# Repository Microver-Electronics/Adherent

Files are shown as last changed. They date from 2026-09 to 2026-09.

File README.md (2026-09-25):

<p align="center">
  Adherent360 APDU — 70 lanes, 10 LANECTRL assemblies, four controller roles
</p>

<p align="center">
  <a href="SYS/ADHERENT_Electrical_Tables.xlsx"><strong>Component spreadsheet</strong></a> &nbsp; · &nbsp;
  <a href="SYS/ADHERENT_System_Wiring_Diagram.png"><strong>System diagram</strong></a> &nbsp; · &nbsp;
  <a href="SYS/ADHERENT_Harness_Wiring_Diagram.png"><strong>Harness diagram</strong></a> &nbsp; · &nbsp;
  <a href="SYS/ADHERENT_Design_Review.pptx"><strong>Design presentation</strong></a> &nbsp; · &nbsp;
  <a href="SYS/ADHERENT_Project_Review.md"><strong>Review findings</strong></a>
</p>

## The project

Adherent360 APDU is an automated pharmaceutical dispensing system built around **70 conveyor lanes**, a gantry, a labeling mechanism and monitored access doors. This repository holds the electrical architecture, component registers, mechanical references and planned hardware/firmware work for the system.

**Current system documents use stable, revision-free filenames.** Electrical design documentation is maintained by **Blackocean Technologies** in the **Microver Electronics / Adherent** repository.

> [!IMPORTANT]
> This is a design-review baseline. Components marked **TBC**, **candidate** or **HOLD** still need selection or engineering validation. LANECTRL Altium design files and exports are present; production release is not confirmed. Firmware/application implementations have not been added yet.

## 🗂️ Start with the documents

- **[Components and part numbers](SYS/ADHERENT_Electrical_Tables.xlsx)** — One sheet with 32 grouped entries, matching diagram references, part numbers, clickable source and CAD links, locations and rough dimensions.
- **[Mechanical BOM](MEC/ADHERENT_Mechanical_BOM.xlsx)** — gantry parts and mechanical procurement references.
- **[Design review presentation](SYS/ADHERENT_Design_Review.pptx)** — architecture, confirmed decisions and questions to resolve.
- **[Project decisions](brain.md)** — working assumptions, naming conventions and current scope.

Included components and interface positions are identified separately from purchased assemblies. Do not sum every spreadsheet row as an independent purchase quantity.

## 🔌 Electrical system

<a href="SYS/ADHERENT_System_Wiring_Diagram.png">
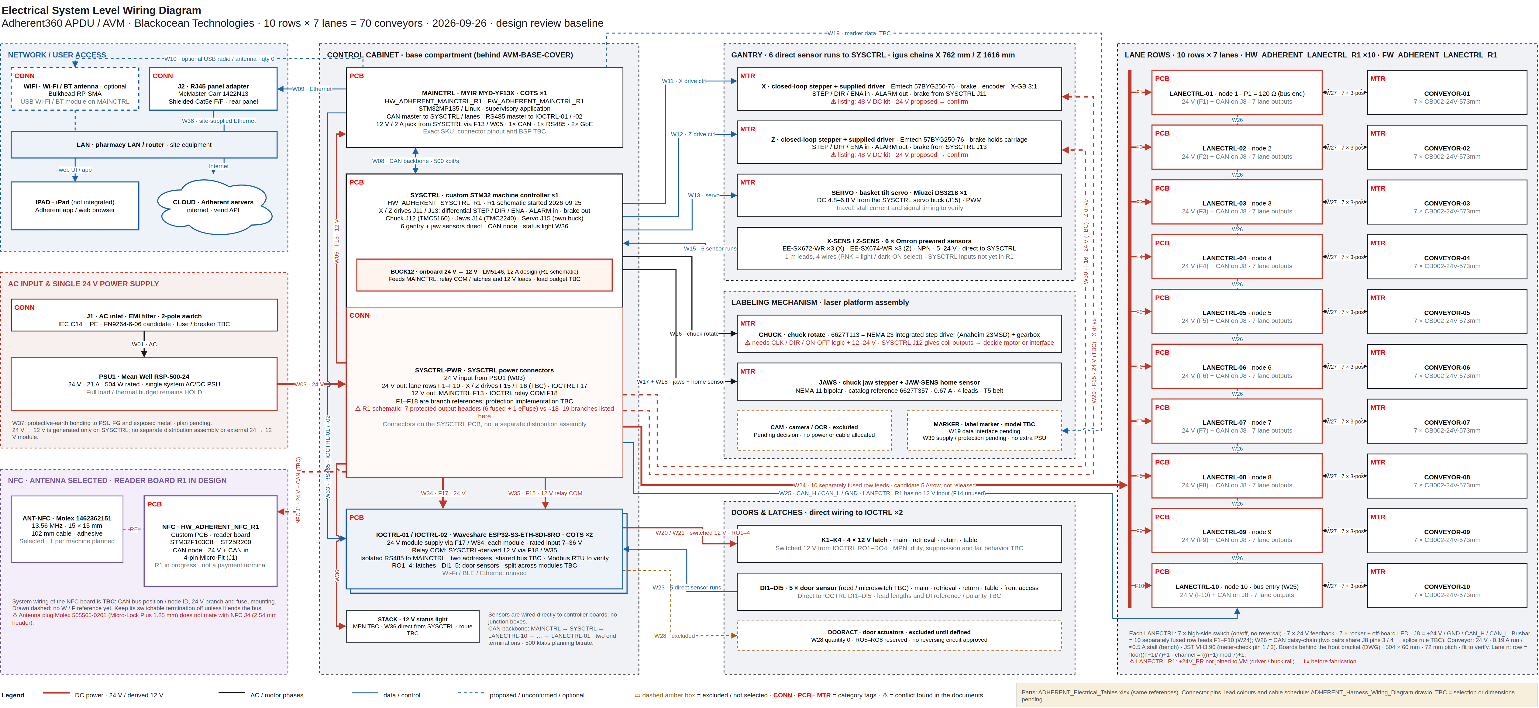
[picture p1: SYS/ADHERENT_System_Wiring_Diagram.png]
Electrical system wiring diagram with red CONN, PCB and MTR category tags
  
</a>

**[Open full-size PNG](SYS/ADHERENT_System_Wiring_Diagram.png)** · **[Edit in draw.io](SYS/ADHERENT_System_Wiring_Diagram.drawio)**

**Pin-level harness:** [ADHERENT_Harness_Wiring_Diagram](SYS/ADHERENT_Harness_Wiring_Diagram.drawio) ([PNG](SYS/ADHERENT_Harness_Wiring_Diagram.png)) shows every device with its product photo, connector pins and lead colours. Its draw.io layers are the build steps (AC → 24 V → branches → CAN → Ethernet / RS485 → drives → labeling → sensors → doors → lane rows), and two further pages hold the cable schedule and the connector reference. Interface conflicts found in the documents are flagged in red there.

Red, bold corner tags identify **CONN** connectors, **PCB** controller boards and **MTR** motor assemblies. These are category labels; the existing board, connector and cable identifiers remain the references used in the schedules.

- **Power:** one Mean Well **RSP-500-24**, rated 24 V / 21 A / 504 W. SYSCTRL generates the derived 12 V rail on board; converter selection and the full load budget remain open.
- **Control network:** CAN links MAINCTRL, SYSCTRL and the ten LANECTRL boards. The two IOCTRL modules (IOCTRL-01, IOCTRL-02) use a separate RS485 connection to MAINCTRL; bus topology and addressing are TBC.
- **Site connection:** McMaster-Carr **1422N13** rear-panel Ethernet adapter, quantity one. The iPad is external and uses the site network.
- **Direct sensors:** six gantry sensors connect to SYSCTRL; five door sensors connect to IOCTRL (split between the two modules TBC). **No junction boxes.**
- **IOCTRL power:** 24 V supplies each module; a separate SYSCTRL-derived 12 V feed supplies the latch relay contacts. Feed branches for the second module are TBC.

### NFC antenna

**Molex 1462362151** is selected: 13.56 MHz, 15 x 15 mm, adhesive mount, 102 mm cable. The NFC reader/front-end, host interface and power budget remain open under O16; no payment terminal is selected. [Supplier listing](https://www.digikey.com/en/products/detail/molex/1462362151/15204370).

The presentation covers the used system interfaces and current SYSCTRL/NFC architecture. Use the single-sheet parts workbook for part numbers, source links and mounting references.

## 🧩 Four controller roles

### 🟦 MAINCTRL — supervisory control

**MYIR MYD-YF13X · purchased board · 1 assembly**  
Planned Linux application, site/server communication, CAN master and RS485 master. Exact order code, populated interfaces and BSP require confirmation. [Hardware folder →](HW/HW_ADHERENT_MAINCTRL_R1)

### 🟪 SYSCTRL — machine control

**Custom STM32 PCB · 1 assembly**  
Gantry and labeling interfaces, sensors, servo and auxiliary outputs, plus onboard 24 V-to-12 V conversion. [Hardware folder →](HW/HW_ADHERENT_SYSCTRL_R1)

### 🟩 LANECTRL — conveyor rows

**Custom STM32G0B1 PCB · 10 assemblies · R1 placed and routed, not released**  
Seven conveyor channels per row, switched on/off by two TPS4H160 high-side switches with current sensing and fault reporting. Each lane has a PCB-mounted rocker switch that is hardware-ANDed with the MCU enable, a 24 V dry-contact feedback input and an off-board lane LED. Each board takes 24 V and CAN on one 4-pin Micro-Fit (+24 V / GND / CANH / CANL). Lane connectors are 3-pin Micro-Fit (24 V / GND / SIGNAL). The CAN node ID is set with a DIP switch and termination with a jumper. The PCB is 504 × 60 mm with 4 layers. Ten rows provide **70 channels**. [Hardware folder →](HW/HW_ADHERENT_LANECTRL_R1)

> [!WARNING]
> LANECTRL R1 schematic: the protected 24 V rail (`+24V_PR`) is not connected to the driver/buck rail (`VM`). Fix this and regenerate the netlist, BOM and PDF before fabrication. See [brain.md](brain.md#lanectrl--custom-pcb-quantity-10).

### 🟧 IOCTRL — door inputs and latch outputs

**Waveshare ESP32-S3-ETH-8DI-8RO · purchased board · 2 assemblies (IOCTRL-01, IOCTRL-02)**  
Eight relays and eight isolated digital inputs per module, 16 of each in total. The baseline allocates four latch outputs and five door-sensor inputs; their split between the two modules and the second module's additional functions are TBC. RS485 firmware behavior needs validation. [Hardware folder →](HW/HW_ADHERENT_IOCTRL_R1)

**Two custom PCB designs, eleven custom assemblies, three purchased controller assemblies (MAINCTRL ×1, IOCTRL ×2).**

## ⚙️ Mechanical integration

- [Machine assembly STEP](MEC/AVM-FRAME-MAINASSEMBLY_V4.STEP)
- [LANECTRL front-bracket DWG](MEC/01_CAD_MODELS/Draw%C4%B1ng/LANE%20DRAWING%20SPACE%20FOR%20UMIT.DWG)
- [Board STEP models and qualification notes](MEC/Board_STEP_Models/README.md)
- [Conveyor supplier reference](SYS/Conveyor%20belt%28CB002-24V-573mm%29.pdf)

The front bracket follows the supplied DWG. LANECTRL R1 is 504 × 60 mm with 8 × M3 holes and switches at a 72 mm lane pitch; its fit against the DWG, switch/LED alignment and cable clearance still need checking. Provisional reconstructed STEP models support placement studies and are not verified fabrication geometry.

## 📁 Repository map

```text
Adherent/
├── SYS/       Current diagram, spreadsheets, presentation and references
├── HW/        SYSCTRL, MAINCTRL, LANECTRL and IOCTRL hardware folders
├── FW/        Planned embedded firmware scope
├── SW/        Planned application and host-tool scope
├── MEC/       Machine CAD and mechanical references
├── docs/      Repository presentation assets
└── brain.md   Project decisions and working assumptions
```

The HW folders use the four board identifiers. LANECTRL contains the Altium schematics, routed PCB, libraries, BOMs and STEP/PDF exports (the netlist, BOM and PDF exports predate the latest schematic/PCB edits). Altium work on SYSCTRL has started; MAINCTRL and IOCTRL are purchased boards. See [firmware scope](FW/README.md) and [software scope](SW/README.txt) for implementation status. Large CAD files use **Git LFS**; install Git LFS and run `git lfs pull` after cloning to obtain available tracked CAD content.

## 🛠️ Next engineering milestones

- Confirm the gantry driver/brake interfaces and performance at 24 V.
- Select and validate the SYSCTRL 12 V converter and complete the power budget.
- Fix the LANECTRL R1 `+24V_PR`/`VM` rail error, decide the single-connector CAN harness (T-splice or second connector) and check the board against the bracket DWG.
- Conveyor current measured on the bench (190 mA running, ≈0.5 A stalled). Confirm the feedback reference on a real harness and finish the firmware stall/timeout logic.
- Coordinate motor drivers, transient protection, fuses, wiring and connectors. Resolve the harness conflicts flagged in the harness diagram: CHUCK 6627T113 is an integrated step driver (SYSCTRL J12 gives coil outputs), the NFC antenna plug does not fit NFC J4, SYSCTRL R1 has 7 protected output headers for about 18–19 branches, and LANECTRL J8 needs a CAN splice rule.
- Finalize marker, latch and sensor selections; confirm direct harness lengths and bracket fit.
- Implement and test firmware, startup/fault behavior and system integration.

See [project decisions](brain.md) for unresolved engineering work. The [earlier engineering review](SYS/ADHERENT_Project_Review.md) records the detailed checks; those schedules remain recoverable in Git history.

## Working conventions

- Keep only the current system-document revision in `SYS`; recover superseded revisions from Git history.
- Update the editable `.drawio` and its PNG together. Keep component quantities and identifiers aligned with the single customer parts sheet.
- Use `HW_ADHERENT_<BOARD>_R<REV>`, `FW_ADHERENT_<BOARD>_R<REV>` and the established `WR_ADHERENT_...` harness identifiers.
- Keep selected parts, candidates, excluded options and verified results clearly distinguished.

---

<p align="center"><strong>Adherent360 APDU</strong><br>System engineering by Blackocean Technologies</p>

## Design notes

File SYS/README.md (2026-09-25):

# Adherent system documents

- [Electrical parts sheet](ADHERENT_Electrical_Tables.xlsx): one worksheet, 32 grouped entries. Diagram reference, component, part number, quantity, location, product/source link, STEP/drawing link and rough dimensions in mm.
- [System wiring diagram](ADHERENT_System_Wiring_Diagram.drawio) and [PNG preview](ADHERENT_System_Wiring_Diagram.png): matching part references, no displayed revision tags.
- [Harness wiring diagram](ADHERENT_Harness_Wiring_Diagram.drawio) and [PNG preview](ADHERENT_Harness_Wiring_Diagram.png): pin-level companion with product photos. Page 1 draws every connector pin and lead colour; its draw.io layers are the harness build steps. Page 2 is the cable schedule by step, page 3 the connector reference (board header, mating part, pin map, source). TBC links are dotted and document conflicts are flagged in red. Generated by `.work/gen_harness.py` (photos in `.work/harness_img`).
- [Design review](ADHERENT_Design_Review.pptx): 10 slides covering used system interfaces, current SYSCTRL power architecture and selected NFC antenna.
- [Earlier engineering review](ADHERENT_Project_Review.md): historical validation and open engineering issues.
- [Mechanical BOM](../MEC/ADHERENT_Mechanical_BOM.xlsx) and [board STEP models](../MEC/Board_STEP_Models/README.md).

Use MAINCTRL, SYSCTRL, LANECTRL and IOCTRL everywhere. LANECTRL-01 through LANECTRL-10 are ten instances of HW_ADHERENT_LANECTRL_R1. IOCTRL-01 and IOCTRL-02 are two identical Waveshare ESP32-S3-ETH-8DI-8RO modules. CONVEYOR-01 through CONVEYOR-10 identify row groups, each containing seven CB002-24V-573mm conveyors. References are identical in the diagram and parts sheet.

TBC means not confirmed. Missing part selections, source links and dimensions remain explicitly marked. MAINCTRL and IOCTRL STEP models are provisional; the IOCTRL reconstruction uses a PoE reference whose fit to the selected non-PoE variant is unverified. Internal SYSCTRL functions are not additional purchased assemblies. Zero-quantity rows identify excluded or external blocks.

Detailed multi-tab engineering schedules and the previous component register are retained in Git history at commit aef502b. They are superseded as customer deliverables by the single parts sheet. No junction boxes are used.

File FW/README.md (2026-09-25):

# Adherent firmware

No firmware implementation or build has been added yet. Planned project identifiers:

- FW_ADHERENT_MAINCTRL_R1: MYIR Linux supervisor, site networking, CAN and RS485 master.
- FW_ADHERENT_SYSCTRL_R1: gantry/labeling motion, sensors, outputs and fault handling.
- FW_ADHERENT_LANECTRL_R1: STM32G0B1RET6, ten CAN nodes (SN65HVD231; node ID from the 4-bit DIP switch S1, CAN_RS controlled by the MCU). Drives seven conveyor channels on/off through 2 × TPS4H160 (EN_LANEx ANDed with the rocker switch in hardware). Reads current sense (DRV_CS1/2 with SEH/SEL multiplexing), FAULT, 24 V rail (VM_SENSE), seven 24 V feedback inputs (LANEx_SIG) and seven switch states, and drives seven lane LEDs plus status/CAN LEDs. USB-C device port for service. Needed: stall/timeout stop (no limit switch; about 0.5 A stall measured) and the rule that feedback is valid only while the lane is energised.
- FW_ADHERENT_IOCTRL_R1: Waveshare RS485 integration on two modules (IOCTRL-01, IOCTRL-02) with distinct RS485 addresses; selected firmware behavior requires validation.

Six gantry sensors connect directly to SYSCTRL and five door sensors directly to IOCTRL (split between the two modules TBC). No junction boxes. Each IOCTRL module is powered from 24 V; relay contacts switch separate SYSCTRL-derived 12 V.

Define and test protocol/register maps, watchdogs, motor concurrency, startup and power-loss states, and motion/access interlocks before release. See R27 electrical workbook OpenItems. Hardware pin assignments and current limits are not released.

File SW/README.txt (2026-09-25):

Adherent APDU software

Reserved for host tools, applications and integration utilities. No implemented application or build is currently provided here.

The planned system uses MYIR MAINCTRL, site Ethernet through McMaster 1422N13, an external iPad app/browser and Adherent server interfaces. Authentication, QR onboarding, site network policy and optional features remain to be defined.

Firmware scope: ../FW/README.md. Current design: ../SYS/ADHERENT_Electrical_Tables.xlsx and ../brain.md.

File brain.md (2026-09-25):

# Adherent APDU project brain

Last updated: 2026-09-26

Project: Adherent360 APDU / AVM pharmaceutical vending machine.
Working repository: https://github.com/Microver-Electronics/Adherent
Electrical design company: Blackocean Technologies.

This file records project decisions and working assumptions. A diagram label or a candidate part is not proof of datasheet compatibility. Distinguish confirmed requirements from proposed implementation details when continuing the design.

## Current deliverables

- Project landing page: [README](README.md), with current document links, diagram preview, controller roles and implementation status. Banner source: `docs/assets/adherent-banner.svg`.
- Current system diagram: [Electrical System Level Wiring Diagram R27](SYS/ADHERENT_System_Wiring_Diagram.drawio).
- Diagram preview: [R27 PNG](SYS/ADHERENT_System_Wiring_Diagram.png).
- Pin-level harness diagram: [ADHERENT_Harness_Wiring_Diagram](SYS/ADHERENT_Harness_Wiring_Diagram.drawio) + [PNG](SYS/ADHERENT_Harness_Wiring_Diagram.png). Page 1 = devices with product photos, connector pins, lead colours and conductor-level wires; each build step is a draw.io layer. Page 2 = cable schedule by step, page 3 = connector reference. Generated by `.work/gen_harness.py` (photos in `.work/harness_img`). `SYS/ADHERENT_System_Wiring_Diagram_.drawio` / `.png` (trailing underscore) is the user-supplied style example and is left unchanged.
- Electrical workbook: [APDU Electrical Tables R27](SYS/ADHERENT_Electrical_Tables.xlsx). BOM, interfaces, cables, protection, power model and open engineering items.
- Presentation: [Design Review Questions R27](SYS/ADHERENT_Design_Review.pptx). Aligned with the current diagram and workbook.
- Component/part-number register: [System Diagram Components R27](SYS/ADHERENT_Electrical_Tables.xlsx), 82 rows including interfaces and explicit external/options.
- [Review findings](SYS/ADHERENT_Project_Review.md).
- Superseded SYS revisions and the older unversioned presentation were removed from the working folder; recover them from Git history when needed.
- Mechanical model handoff folder: [Board STEP Models](MEC/Board_STEP_Models/README.md).
- LANECTRL front metal bracket reference: [LANE DRAWING SPACE FOR UMIT.DWG](MEC/01_CAD_MODELS/Draw%C4%B1ng/LANE%20DRAWING%20SPACE%20FOR%20UMIT.DWG). User confirms the bracket is being made to this drawing; PCB fit and clearances have not yet been checked.
- Hardware folders: `HW/HW_ADHERENT_SYSCTRL_R1`, `HW/HW_ADHERENT_MAINCTRL_R1`, `HW/HW_ADHERENT_LANECTRL_R1`, `HW/HW_ADHERENT_IOCTRL_R1`.
- Rear-panel Ethernet connector J2: **McMaster-Carr 1422N13**, quantity 1 per system, replaces the previous Neutrik candidate. Shielded Cat5e RJ45 female/female, screw-on mounting, black plastic housing; 0.95 in (24.13 mm) panel cutout and 0.14 in mounting holes, mounting fasteners included. [Product](https://www.mcmaster.com/product/1422N13), [supplier specifications](https://www.mcmaster.com/products/data-transmission-couplers/).

## Confirmed decisions

- Ten rows, seven lanes per row: 70 conveyor channels.
- One conveyor motor per lane. One momentary button and one LED per lane.
- Only one AC/DC PSU remains: **PSU1, Mean Well RSP-500-24**, rated 24 V / 21 A / 504 W. Recalculate the combined power budget before treating its capacity as sufficient.
- The separate 12 V and 48 V PSUs were removed.
- **24 V to 12 V conversion is on the custom SYSCTRL PCB.** There is no separate cabinet DC/DC module.
- The customer requires CAN for the custom-board network.
- IOCTRL is an explicit exception: **both IOCTRL modules (IOCTRL-01, IOCTRL-02) connect to MAINCTRL over RS485**. Their Ethernet and wireless functions are unused.
- **IOCTRL quantity is 2 per system** (customer/user decision, 2026-09-25). Supersedes the earlier quantity of 1.
- No Ethernet switch in the system. Provide a hardwired Ethernet connection to the site network.
- The iPad is external and uses the customer's app or a browser; it is not integrated into the cabinet.
- LANEPANEL was merged into LANECTRL. There is no separate LANEPANEL PCB.
- Cellular connectivity and UPS/battery backup were rejected during the meeting as unnecessary.
- Camera/OCR is outside the current baseline and remains a customer question.
- The customer requested no emergency stop. This is a recorded scope decision, not a completed machine safety assessment.

## NFC antenna selection

- User-selected antenna: **Molex 1462362151**, planning quantity 1 per machine.
- Manufacturer: 13.56 MHz, 2.40 uH, 15 x 15 x 0.27 mm, adhesive mount, 102 mm cable.
- [Molex](https://www.molex.com/en-us/products/part-detail/1462362151), [selected DigiKey listing](https://www.digikey.com/en/products/detail/molex/1462362151/15204370).
- This is an antenna, not a complete reader. Reader/front-end, matching, termination, host interface, board allocation, mounting and supply remain TBC under O16. Payment-terminal functionality is not selected.
- Antenna cable is included in the component; do not order it again as a generic patch cable. Any reader power/host harness is still undefined.
- Lead (Molex drawing): 102 mm twisted pair, red / black, 28 AWG, housing **Molex 505565-0201** (Micro-Lock Plus 1.25 mm) with 505431-1000 terminals. **It does not mate with NFC R1 J4** (Würth 61300211821, 2.54 mm pin header): change J4 to a Micro-Lock Plus 2-circuit header or re-terminate the lead.

## Boards

### MAINCTRL — off the shelf, quantity 1

- **MYIR MYD-YF13X**, STM32MP135-based Linux development board.
- Replaces the previously considered MYD-LT527-SX; do not reintroduce that product or its price/specifications.
- Supervisory application, site/server communication, CAN master and RS485 master.
- Base-board supply requirement recorded from MYIR documentation: 12 V / 2 A. Feed from the SYSCTRL-derived 12 V rail, not directly from 24 V.
- Exact populated order code, Ethernet capabilities, BSP and radio accessories require verification against the purchased variant. Some older deliverables contain unverified Gigabit claims.
- Official product page: https://www.myirtech.com/list.asp?id=727
- Product document: https://www.myirtech.com/download/STM32/MYD-YF13X.pdf

### IOCTRL — off the shelf, quantity 2

- **Two identical modules per system: IOCTRL-01 and IOCTRL-02** (decision 2026-09-25; previously 1). Same product and variant for both.
- Combined capacity: 16 relay outputs and 16 isolated digital inputs.

- **Waveshare ESP32-S3-ETH-8DI-8RO**, RS485 version with standard Ethernet port. Do not substitute the CAN `-C` or PoE version without a decision.
- Eight relay outputs and eight isolated digital inputs.
- Module input range 7–36 V; current design powers the module from 24 V.
- RS485 connection to MYD-YF13X. Modbus RTU firmware is planned; do not assume the factory firmware meets the required protocol and behavior without testing.
- Proposed: both modules on one multi-drop RS485 bus from MAINCTRL, with distinct Modbus slave addresses and termination at the two bus ends only. Topology (shared bus vs two MAINCTRL ports), addressing and termination are **TBC**.
- RO1–RO4 switch four 12 V electromechanical latches: main, retrieval, return and table doors.
- Relay COM receives **separate 12 V derived on SYSCTRL**. The module's 24 V input does not supply or convert the relay-contact voltage.
- DI1–DI5 are allocated to door sensors in the diagram. RO5–RO8 remain reserved for undefined actuator requirements.
- The latch/door-sensor allocation above describes the original single module. **How the four latches, five door sensors and any new functions are split between IOCTRL-01 and IOCTRL-02 is TBC.** The functions assigned to the second module have not been defined; do not invent them.
- Power: two module 24 V feeds and 12 V relay-contact feeds must be accounted for (per-module or shared branches TBC; see W34/W35).
- Ethernet, Wi-Fi and BLE unused.
- Official documentation: https://www.waveshare.com/wiki/ESP32-S3-ETH-8DI-8RO

### SYSCTRL — custom PCB, quantity 1

- `HW_ADHERENT_SYSCTRL_R1` / `FW_ADHERENT_SYSCTRL_R1`.
- STM32 machine controller; combines the former motion-control and auxiliary-I/O functions. The current IOCTRL name refers to the separate Waveshare relay/input module.
- Gantry drive control interfaces, brake control, basket servo control, optical sensors, labeling stepper drivers and auxiliary outputs.
- **Onboard 24→12 V buck supplies the existing 12 V loads**, including local circuitry, MAINCTRL and latch contacts. LANECTRL R1 does not use 12 V: it takes only 24 V and generates its own 5 V / 3.3 V.
- Buck topology, MPN, current capacity, protection, thermal design and sequencing are not validated.
- Local servo voltage conversion remains necessary; DS3218 is not a direct 12 V or 24 V load (supplier: DC 4.8–6.8 V).
- **R1 schematic snapshot** (Altium project started 2026-09-25; netlist export 2026-09-25 20:17 — early draft, most connector pins not yet on nets):
  - J1 Phoenix 1757242 (2-pos 5.08 mm) input; same sheet: LM74700 ideal-diode controller, 2 × CSD18540, SMDJ33A TVS.
  - 12 V: LM5146 buck, sheet title "24VIN, 12V-12A OUT"; logic rails LMR33630 + TLV75733.
  - Protected outputs: board fuses F1–F7 (4 A / 72 V); by placement F1→J4, F2→J5, F3→J6, F5→J8 (5-pin), F6→J9 (5-pin), F7→J10, F4 without a header; J7 behind a TPS16637 eFuse. Rails not yet defined. **The harness needs about 18–19 protected branches** (10 row feeds, X / Z drives, IOCTRL, NFC, marker, MAINCTRL 12 V, relay COM, stack light) — R1 provides 7 output headers (6 fused + 1 eFuse). Note: R27 branch IDs F1…F18 (e.g. F1…F10 row feeds, F13 MAINCTRL) are not the R1 board fuse designators.
  - X / Z drive: J11 / J13 Micro-Fit 43045-1000: 1 PUL+ · 2 PUL− · 3 DIR+ · 4 DIR− · 5 ENA+ · 6 ENA− (AM26C31 differential) · 7 ALM_IN (4k7 pull-up) · 8 GND · 9 +24V_MOT · 10 BRK− (DMN6140 low side). Only J11.7, J11.9, J13.9 and J13.10 reach circuitry so far. J13 nets are named `_Y` but drive Z → rename.
  - Chuck: J12 43045-0400 ← TMC5160 + BSC072N08 bridge (BMA1 / BMA2 / BMB1 / BMB2). Jaws: J14 43045-0400 ← TMC2240 (OUT1A / OUT2A / OUT1B / OUT2B).
  - Servo: J15 Molex 43650-0300 on the sheet with TPS54560 buck, INA181 current sense and 74AHCT1G125 buffer; pin map TBC.
  - CAN: SN65HVD232 with switchable 112 Ω termination (2 × 56 Ω in series through the CPC1014 contact, CAN_TERM; NFC R1 uses the same circuit); no bus connector placed yet. Keep the termination off (SYSCTRL is not a bus end).
  - Not yet in R1: gantry / jaw sensor inputs, stack-light outputs, ten row feeds, CAN connector. Service: J2 UART, J3 SWD.

### LANECTRL — custom PCB, quantity 10

- `HW_ADHERENT_LANECTRL_R1` / `FW_ADHERENT_LANECTRL_R1`. Altium project in `HW/HW_ADHERENT_LANECTRL_R1`, designer Umit KAYACIK (Microver title block). Schematic R1 "Initial Release" 2026-09-23; PCB placed and routed; STEP re-exported 2026-09-25.
- One board per row: seven conveyor channels, seven feedback inputs, seven rocker switches and seven lane-LED outputs. Includes the former LANEPANEL functions.
- Facts below come from the current SchDoc/PcbDoc files (checked 2026-09-25). The Protel netlist, BOMs and schematic PDF in the folder are older than the latest schematic/PCB edits; regenerate them before any release.

**Architecture (as designed, supersedes the R27 "H-bridge / 12 V lane logic" description)**

- Motor drive: **2 × TI TPS4H160BQPWPRQ1** 4-channel high-side smart switches (U7: lanes 1–4, U9: lanes 5–7, U9 channel 4 unused). On/off only: no H-bridge, no PWM speed control, no reversal. Current limit R_CL = 1.2 kΩ (R62/R71), current-sense R_CS = 604 Ω (R65/R75) to MCU ADC; FAULT, SEH/SEL and DIAG_EN to MCU. R62/R65/R71/R75 values are marked "?" in the schematic and still need confirmation.
- Hardware interlock: each lane input = rocker switch **AND** MCU enable (2 × SN74HCS08, EN_LANEx with 10 k pull-downs). A lane cannot run with its switch off, and cannot run without MCU enable.
- MCU: **STM32G0B1RET6** (LQFP64), 8 MHz crystal ECS-80-8-30Q-VS with 8.2 pF load caps. SWD on Samtec FTSH-103 (J9). USB-C (J10, USB 2.0 device, 5.1 k CC pull-downs, CMC + ESD) for service/programming.
- CAN: **SN65HVD231** (3.3 V) + ACT45B common-mode choke. CAN_RS driven by MCU (R44 pull-up keeps the node in standby at reset). **120 Ω termination selected with 2-pin jumper P1** (Molex 22-03-2021 + R43). Node ID from **4-position DIP switch S1** (Würth 418121270804, NODE_ID0–3).
- Power: single **24 V input**. Chain: F1 0452005 (5 A) → SMDJ24CA TVS → LM74700-Q1 + BSC028N06NS ideal-diode reverse protection → bulk 2 × 220 µF → motor rail; LMR50410 buck 24 V → 5 V (88.7 k / 22.1 k, VREF 1.0 V → 5.0 V) → AMS1117-3.3, with USB VBUS OR-ed in through MBR0520 diodes. VM_SENSE divider 100 k / 10 k to ADC. **The board has no 12 V input; lane logic is powered from its own 24 V input.**
- Lane connector: **7 × Molex Micro-Fit 3.0 43650-0300** (3-pin, right angle), pin 1 = switched 24 V (LANE_OUTx), pin 2 = GND, pin 3 = SIGNAL. SMF33A TVS on outputs and signal lines (the default BOM variant leaves D10 not fitted).
- SIGNAL input: 24 V dry contact → 10 k pull-down at connector, 100 k / 15 k divider (24 V → 3.13 V), BAT54WS clamp to 3.3 V, RC filter, to MCU GPIO.
- Bus connector: **one Molex Micro-Fit 3.0 43045-0400 (2 × 2, 4-pin): 1 = +24 V, 2 = GND, 3 = CANH, 4 = CANL.** There is no second (bus-out) connector on the board; daisy-chaining the CAN bus between rows therefore needs a harness-level solution (T-splice / Y-cable) or a board change. **Open decision.**
- User interface: 7 × C&K **300SP1J1BLKM2RE** PCB-mount rocker switches (SPDT ON–ON, 3.3 V logic level). Lane LEDs are **off-board**: 7 × 2-pin 2.54 mm headers LEDS1–LEDS7 on the switch side, driven from MCU GPIO through 100 Ω (R50–R56). The LED part and its mounting in the bracket are TBC. The earlier on-board LED footprints D29–D35 (Würth 150080VS75000) were removed from the PCB but still appear in the exported BOM/netlist. Board status LEDs D25 (power), D27 and D28 (LED_STAT, LED_CAN) are SMD parts on the bottom side.
- PCB: **504.0 × 60.0 mm**, 4 layers (Top / Int1 GND / Int2 PWR / Bottom), about 1.6 mm total thickness. Top side carries only the THT rocker switches, LED headers and mounting holes; **all SMD parts are on the bottom side**. Lanes run in order along the board: J7…J1 from left to right at **72.0 mm pitch**, J8 at the right end next to lane 1, USB-C at the bottom edge centre (x ≈ 272 mm). **8 × M3 mounting holes** at x = 6 / 167 / 343 / 498 mm and y = 6 / 54 mm from the lower-left corner (MTG2 at y = 55 mm, 1 mm off the others; confirm this is intentional).
- Previously listed candidates **Omron B3F-4055, Kingbright WP7113ID and DRV8876 are superseded** by the design above.

**Critical schematic error (found 2026-09-25, must fix before fabrication)**

- In `04_POWER.SchDoc` the protected rail after M1 carries power port **+24V_PR**, while the TPS4H160 VS pins (`08_DRIVER`) and the LMR50410 VIN/EN use power port **VM**. Nothing joins +24V_PR and VM, and the PcbDoc also holds them as two separate nets. As drawn, neither the motor switches nor the 5 V/3.3 V logic would receive power. Rename one port (or add the connection), recompile, update the PCB from the schematic and re-run DRC.

**Other open LANECTRL items**

- Recompile and regenerate the netlist, BOMs (both variants) and schematic PDF. The current PDF shows an empty block-diagram page, but `02_BLOCK_DIAGRAM.SchDoc` now embeds the A3 block-diagram image. The PcbDoc still uses NetS1_x names where the schematic now has NODE_ID0–3 (ECO pending).
- Only B1 (ferrite bead) lacks an MPN in the BOM. The variant name is still the default "Variant of HW_ADHERENT_LANECTRL_R1".
- LM74700 symbol pin naming, BAT54WS footprint polarity and TPS4H160 R_CL/R_CS values need final review.
- Bracket fit: check the 504 × 60 mm outline, hole pattern, switch positions and LED header positions against `LANE DRAWING SPACE FOR UMIT.DWG`.
- The current board model is `MEC/HW_ADHERENT_LANECTRL_R1/HW_ADHERENT_LANECTRL_R1(Variant of HW_ADHERENT_LANECTRL_R1).step` (identical export in the Altium Project Outputs). Older copies are in `MEC/01_CAD_MODELS/` and `MEC/Board_STEP_Models/LANECTRL_Custom/`.
- `HW/HW_ADHERENT_LANECTRL_R1/HW_ADHERENT_LABELCTRL_R1/` is a separate KiCad project nested inside the LANECTRL folder. It is not part of LANECTRL; move it to its own HW folder once its scope is defined.

**Conveyor interface facts used by LANECTRL**

- Customer bench measurement at 24 V (`Docs/New_Docs/information.txt`): 190 mA running, 280–310 mA with manual braking, about 0.5 A when stalled by hand. The SIGNAL line switches between 0 V and 24 V when the feedback plate moves (24 V dry contact); the board must read it and stop the motor.
- Supplier internal schematic (`Docs/Müşteriden gelen dosyalar/`): the motor is fed through series diode D3 and has freewheel diode D1 and capacitor C1. The plate switch S1 connects the supply to the signal pin through D2. The SIGNAL level is therefore only valid while that lane is energised. The drawing's pin numbering is the reverse of the datasheet (pin 1 = +24 V, pin 3 = SIGNAL). LANECTRL follows the datasheet; confirm on a real conveyor with a meter. Reversed polarity is blocked by D3 rather than shorted.
- Firmware still needs a stall/timeout strategy using current sense, because the conveyor has no limit switch.

## Latest SYSCTRL representation correction

- SYSCTRL and the former lower distribution box are one PCB assembly. The lower area represents SYSCTRL power connectors, not a separate distribution assembly.
- Show one onboard 24 V-to-12 V SMPS block. PSU1 supplies 24 V to SYSCTRL; external loads connect through SYSCTRL.
- Removed the misleading external W04/W06/W07 loop arrows between those two boxes. Their previous external-harness descriptions must not be used as released wiring.
- F1–F18 remain branch references; the previous 17-DIN-holder placement is not confirmed by this correction. Final protection implementation and connector pinouts remain TBC.
- Electrical tables and component register now reflect this correction. W04/W06/W07 have zero external-harness quantity; DIN-holder procurement is withdrawn. Presentation remains an earlier review snapshot and must be refreshed before presenting the current topology/NFC scope.

## R27 power routing and identifiers

- W03: PSU1 24 V output directly to SYSCTRL system input; connector MPN/pins TBC.
- W06 internalized: F11 is an internal SYSCTRL motor-rail protection reference, not an external jumper.
- W07 internalized: F12 is the onboard SMPS input branch; no separate external input cable.
- W04 internalized: onboard SMPS output feeds internal SYSCTRL 12 V routing; no separate distribution rail assembly.
- W05 / F13: derived 12 V to MAINCTRL.
- F14: lane-logic protection on SYSCTRL; 12 V passes into the CAN/lane harness. **Superseded by LANECTRL R1:** the board has no 12 V input, so the 12 V conductor in W25 and branch F14 are no longer needed for the lane rows. Remove them at the next diagram/workbook revision, or record a new use.
- W24 / F1–F10: 24 V row feeders. With LANECTRL R1 each row's 24 V (motors and logic) and CAN share one 4-pin Micro-Fit (43045-0400: +24 V / GND / CANH / CANL). How W24 and the W25 CAN backbone merge into a harness is **TBC**, because the board has only one bus connector.
- W29 / F15 and W30 / F16: proposed 24 V gantry drive feeds, pending supplier confirmation.
- W34 / F17: 24 V IOCTRL module power. With two IOCTRL modules, per-module feeds or a shared branch are TBC; cable quantity and fuse rating need updating.
- W35 / F18: derived 12 V feed to IOCTRL relay contacts. Second-module relay-contact feed TBC; 12 V converter load depends on the latches actually switched.
- W33: MAINCTRL–IOCTRL RS485. Now serves two modules; add the IOCTRL-01 to IOCTRL-02 segment (or a second run) once topology is fixed.
- W02, W31 and W32 retired with the removed PSUs. W14 and W22 retired with the cancelled intermediate sensor trunks.
- W15: six direct gantry sensor runs to SYSCTRL. W23: five direct door sensor runs to IOCTRL (module split TBC). No junction boxes.
- W36 status light, W37 PE bonding, W38 site-supplied Ethernet and W39 unresolved marker supply are explicitly scheduled.
- Fuse ratings, wire sizes, connector loading, DC/DC losses and simultaneous motor loads need recalculation. Older spreadsheet currents are estimates, not verified sizing.

## Communication

- Proposed CAN backbone: MAINCTRL → SYSCTRL → LANECTRL-10 through LANECTRL-01.
- Diagram baseline: CAN 2.0B, 500 kbit/s, termination at MAINCTRL and LANECTRL-01. Validate implementation and cable routing.
- LANECTRL R1 implementation: termination is fitted with jumper P1 (only on the end-of-bus board). The CAN node ID is set with the 4-bit DIP switch S1 (16 addresses, 10 used). The single 4-pin bus connector means the backbone needs T-splices or Y-cables at each row unless a second connector is added.
- Separate RS485 link: MAINCTRL ↔ IOCTRL-01 and IOCTRL-02 (proposed shared multi-drop bus; TBC).
- Site Ethernet connection serves the external iPad/app and server communication. Optional Wi-Fi/BLE arrangements remain distinct from rejected cellular connectivity.

## Motors and mechanisms

Current inventory is **75 motors across five model/part-reference groups**, excluding undefined door actuators:

- Conveyor motors: 70 brushed DC geared motors, one per lane. **CB002-24V-573mm is the conveyor assembly model**, not a confirmed standalone motor MPN. Driven on/off by TPS4H160 high-side switches on LANECTRL (no reversal, no PWM). Measured: 190 mA running, about 0.5 A when stalled by hand.
- Gantry X/Z: 2 × **Emtech 57BYG250-76**, NEMA23 closed-loop steppers. Mechanical BOM states brake and driver included. **Whether drivers are integrated into the motors or separate modules is unconfirmed.** X includes a 3:1 gearbox.
- Basket tilt: 1 × **Miuzei DS3218** servo; drive electronics are internal. Exact variant and supply range need confirmation before final regulator selection.
- Chuck rotation: 1 × NEMA23; **6627T113** is the recorded CAD/catalog reference. The McMaster manual identifies it as **Anaheim 23MSD006S-00-00-00, an integrated step motor + driver** (sinking inputs): 7-pin input AMP 640440-7 / CBL-AA4031 — 1 DIR BRN · 2 CLK RED · 3 ON/OFF ORN · 4 MS2 YEL · 5 MS1 GRN · 6 +12–24 VDC BLU · 7 0 VDC VIO. **Conflict:** SYSCTRL R1 J12 provides TMC5160 coil outputs. Decide: plain bipolar NEMA 23 on J12, or keep 6627T113 and give SYSCTRL CLK / DIR / ON-OFF logic outputs + a fused 24 V pair.
- Chuck jaws: 1 × NEMA11; **6627T357** (McMaster): bipolar hybrid, 0.67 A / phase, 5.6 Ω, 3.08 mH, 4 leads 26 AWG × 24 in: A+ red · A− blue · B+ green · B− black (McMaster 4-lead diagram). Driven by TMC2240 on SYSCTRL J14; set run current ≤ 0.67 A.
- Emtech listing (X / Z kit): motor lead A+ WHT · A− GRN · B+ BLU · B− BLK (2.0 m); encoder 0.3 m lead + 1.7 m extension, DB15: WHT 0 V · RED +5 V · YEL EB+ · GRN EB− · BLU EA− · BLK EA+. The listing is a **48 V DC** kit; 24 V operation is still only proposed. Driver terminal names are not published in the listing.
- Omron EE-SX672-WR / EE-SX674-WR: 5–24 VDC, NPN open collector 100 mA, 1 m leads BRN +V · BLU 0 V · BLK OUT · PNK L (L open = dark-ON, L to BRN = light-ON). With a 3-wire SYSCTRL input, terminate PNK in the harness.

Do not assume the Emtech drive supports 24 V or any specific STEP/DIR voltage until its exact driver datasheet is available. Earlier drawings overstated integrated-driver status and signal compatibility.

The four electromagnetic latches are not counted as motors. Door actuator models and quantities are undefined; the table-door actuator was excluded from the earlier scope.

## Mechanical inputs and STEP models

- Machine CAD: `MEC/AVM-FRAME-MAINASSEMBLY_V4.STEP`.
- Mechanical BOM: `MEC/ADHERENT_Mechanical_BOM.xlsx`.
- Conveyor reference: `SYS/Conveyor belt(CB002-24V-573mm).pdf`.
- Test-rig reference: `SYS/APDU-Test-Rig-Drawing-Set-BOT-TR-001-RevD.pdf`; this is not the production electrical design.
- Approximate CAD envelope used previously for cable estimates: 855 × 890 × 1905 mm. Treat derived routing lengths as estimates.

### Provisional reconstructed board models

- IOCTRL: `MEC/Board_STEP_Models/IOCTRL_Waveshare_ESP32-S3-ETH-8DI-8RO/IOCTRL_Provisional_Placement_R1.step`.
  - One model covers both IOCTRL placements; cabinet space, DIN mounting and cable clearance must be reserved for **two** modules.
  - Nominal 175 × 90 × 40 mm envelope from the user image.
  - Reference image is the **PoE variant**; compatibility with the selected non-PoE product is unverified.
  - Slots and connector geometry are estimated; DIN clip and antenna are omitted.
- MAINCTRL: `MEC/Board_STEP_Models/MAINCTRL_MYIR_MYD-YF13X/MAINCTRL_MYD-YF13X_Provisional_Placement_R1.step`.
  - Documented PCB outline 137.29 × 105 mm.
  - PCB thickness, hole positions/diameters, connector heights and component envelopes are estimates.
  - Simplified top- and bottom-side components are included.
- Both models passed solid validity and STEP reimport checks. **Geometry validity does not validate dimensional accuracy.** Read each folder's `MODEL_NOTES_R1.md`; use for preliminary placement only, not fabrication.
- No manufacturer IOCTRL STEP download was found in the checked official resources. Manufacturer request draft is saved locally and has not been sent.
- LANECTRL: the STEP model is exported from the routed R1 PCB (`MEC/HW_ADHERENT_LANECTRL_R1/`, 2026-09-25). SYSCTRL still needs a STEP from its PCB layout.

## Documentation and harness conventions

- Use Blackocean Technologies branding; no Melis Electronics branding in new deliverables.
- Avoid personal names in customer-facing deliverables. Use “the team”, “the mechanical team” or “the customer”.
- Document title: **Electrical System Level Wiring Diagram**.
- Keep only current deliverable revisions under `SYS`. Recover older revisions from Git history. No RAR bundles.
- Keep diagram blocks and orthogonal routes spacious, labels legible and arrows clear.
- Put a **red, bold category tag in the upper-left corner inside each applicable component box**: `CONN` for connectors, `PCB` for controller boards, `MTR` for motors. Keep tags attached to their boxes and reserve enough space so they do not overlap content.
- R27 category tags cover 4 connector/interface boxes (RJ45 panel adapter, optional antenna bulkhead AC inlet and SYSCTRL power connectors), 13 controller-board boxes, and 15 motor/assembly boxes (five individual motor groups and ten seven-conveyor row groups). Counts refer to diagram boxes, not physical component quantities.
- Category tags do not replace existing J/W/F identifiers or controller names. Onboard converter sections are not separate PCBs; excluded door actuators remain undefined and are not tagged as selected motors.
- Edit the `.drawio` source and regenerate its PNG together. README embeds the current PNG from `SYS`.
- Bold red arrows carry power only. Data/control paths are blue. Clearly distinguish proposed connections.
- Keep tables in Excel rather than in the diagram. No revision-history or option-item blocks in the diagram.
- English presentation, concise text and useful visuals. Remove unused interface options from the current presentation; retain historical decisions in project records.
- Custom PCB I/O connector preference: Molex Micro-Fit 3.0. Purchased boards retain their native connectors; do not assign Micro-Fit MPNs to incompatible COTS sockets.
- Preferred harness cable: four-conductor 22 AWG, red/black/yellow/green, where electrically suitable. Use appropriately rated exceptions for mains and higher-current circuits.
- No junction boxes. Sensors run directly to controller boards. Use crimped mating connectors on custom boards and the native terminals/connectors on COTS hardware.
- Naming: `HW_ADHERENT_XXX_RY`, `FW_ADHERENT_XXX_RY`, `WR_ADHERENT_AAA_TO_BBB_RY`.
- Preserve custom PCB quantities unless the user explicitly changes the architecture.
- Do not send messages or files to third parties without explicit authorization.

## Outstanding engineering work

1. R27 aligns workbook, component register, presentation and diagram. Resolve OpenItems O01-O16 before engineering release; document consistency does not close physical validation.
2. Size the SYSCTRL 24→12 V converter and review total PSU1 capacity, protection, cable/connector current ratings and power sequencing.
3. Obtain exact Emtech driver/brake documentation; confirm 24 V performance, wiring and driver packaging.
4. Confirm latch current, duty cycle, fail behavior and suppression; define any door actuators separately.
5. Confirm conveyor stall/load current and feedback signal type. Do not equate that signal with verified product dispensing without evidence.
6. Confirm MAINCTRL populated variant, connector dimensions and network specifications.
7. Obtain manufacturer mechanical CAD or verify reconstructed models against hardware.
8. Finalize PCB mounting, harness routing, lengths and service clearances with the mechanical team.
9. Resolve remaining customer questions: camera/OCR, illumination, iPad pairing, NFC/card reader and label marker.
10. Harness conflicts from the 2026-09-26 harness diagram: CHUCK interface (6627T113 integrated driver vs J12 coil outputs), NFC J4 vs antenna plug, SYSCTRL protected-output count (≈18–19 needed, 7 headers in R1), LANECTRL J8 CAN in / out splice rule, gantry-sensor PNK termination, Emtech 48 V vs 24 V, servo buck setpoint 4.8–6.8 V, conveyor pin 1 / 3 meter check, J1 FN9264-6 (6 A) margin vs RSP-500 input up to 5.3 A at 115 VAC, SYSCTRL J1 current rating vs the 24 V load.

## R27 planning checks

- Known PSU peak subtotal: 268.96 W, excluding four unresolved load-current entries (including NFC reader) and marker power. Not a complete capacity approval.
- Seven-conveyor row case: 14.05 A versus candidate 5 A protection; concurrency must be constrained and tested. **Update:** that figure assumed 2 A per conveyor. The measured stall is about 0.5 A, so a row with all seven lanes stalled draws about 3.5 A plus logic, below the 5 A fuse (F1 0452005) on LANECTRL. The TPS4H160 current limit (R_CL 1.2 kΩ) caps each channel. Recalculate the PSU budget with measured values.
- 39 cable IDs, 28 required external types, five missing route lengths; 109.5 m is only the known routing subtotal.
- 18 branch-protection references; physical placement and holder quantities need reconciliation with the merged SYSCTRL connector architecture.
- FW/SW folders contain scope descriptions only, no implemented firmware/application builds.
- HW contains four reserved board folders; no production PCB designs have been added. README must distinguish planned functions from implemented or validated capabilities. **Update 2026-09-25:** LANECTRL R1 is placed and routed (not released; see the critical +24V_PR/VM error above). SYSCTRL R1 and NFC R1 Altium projects have also been started; the SYSCTRL R1 snapshot is summarised in the SYSCTRL section (2026-09-26).

## Local build references

- `.work/r26_diagram.py`: creates R26 from R25; restore the R25 input from Git history before rerunning.
- `.work/r25_diagram.py`: creates R25 from R24; restore the R24 input from Git history before rerunning.
- `.work/r24/`: presentation edit and validation scripts/artifacts from the R24 update.
- Each provisional board-model folder contains `build_ocp_R1.py` and validation output.
- CAD dependencies were installed in `.work/cad-deps`. Direct OpenCascade imports worked; full CadQuery import stalled in VTK. Some dependency access required elevated execution in this environment.
- Render diagrams using the installed draw.io CLI and inspect the PNG before delivery. Check both content and geometry; a successful export alone does not prove correctness.

## Mechanical model location

- Board STEP models are maintained in `MEC/Board_STEP_Models`, alongside machine CAD. Use MAINCTRL, SYSCTRL, LANECTRL and IOCTRL consistently across model folders and system documents.

## Customer handoff and naming — 2026-09-25 (supersedes earlier workbook instructions)

- The customer needs one short worksheet, not detailed electrical schedules. `SYS/ADHERENT_Electrical_Tables.xlsx` is the only current electrical parts workbook: 32 grouped entries with diagram reference, component, part number, quantity, location, clickable source and STEP/drawing links, and rough dimensions in mm.
- Removed the duplicate component workbook. Previous engineering schedules remain in Git history at `aef502b`; preserve engineering decisions recorded above until resolved.
- Current document names use `ADHERENT_<Purpose>` without R27 suffixes. The editable system diagram and PNG share `ADHERENT_System_Wiring_Diagram`. The earlier presentation is explicitly `ADHERENT_Design_Review.pptx`.
- Mechanical BOM is `MEC/ADHERENT_Mechanical_BOM.xlsx`. Board models are under `MEC/Board_STEP_Models`; supplier part numbers and original supplied CAD/drawing names remain traceable.
- Canonical board roles: MAINCTRL, SYSCTRL, LANECTRL, IOCTRL. HW/FW board revision identifiers keep R1 because it identifies the board design rather than the documentation revision.
- Match the visible diagram references to the customer sheet. CONVEYOR-01…10 are row groups of seven; LANECTRL-01…10 are individual row-controller instances. X-GB and JAW-SENS remain subcomponents of their labeled motor blocks.
- No independent distribution box. BUCK12 and SYSCTRL-PWR are internal SYSCTRL functions. No junction boxes.
- Manufacturer/source dimensions and provisional model envelopes must remain distinguished. Missing selections, drawings or dimensions stay TBC. Do not invent mounting dimensions.
- Commit and push completed changes incrementally, as requested by the user.

## Excel compatibility fix — 2026-09-25

- Fixed duplicate `pageMargins` in `ADHERENT_Electrical_Tables.xlsx`, introduced by the print-settings patch. Cell contents, styles, 27 hyperlinks and one-sheet layout are unchanged.
- Both released workbooks passed read-only, normal Microsoft Excel opening. Electrical sheet exported from Excel to exactly one A3 landscape PDF page and was visually checked.
- Published 14-slide presentation and both tracked historical PPTX files opened in Microsoft PowerPoint.
- 72 tracked files passed applicable ZIP CRC, XML/package relationship, PDF parsing, image decoding, JSON or file-signature checks. STEP geometry and DWG mechanical fit are separate from these file-format checks.
- Future workbook checks must reject duplicate singleton worksheet records and include normal Microsoft Excel opening; a Python reader alone does not prove Excel compatibility.

### Expanded repository check after incoming LANECTRL commits

- Integrated upstream `7fbfe32` and `587bbe7` before pushing the Excel fix; no incoming hardware files were discarded.
- Repeated applicable structural checks across all 225 tracked files. Both additional LANECTRL BOM workbooks passed normal read-only Microsoft Excel opening, bringing the native-tested workbook count to four.
- LANECTRL Altium schematics, PCB layout, libraries, BOMs and exported models are now present. Earlier statements that all HW folders were empty no longer describe LANECTRL. Presence and file integrity do not establish production release or resolve electrical design holds.
- Altium binary container signatures and tracked ZIP checks passed. Native Altium editing/compilation and DWG geometric validation were not performed.
- All nine tracked STEP/STP files imported successfully into OpenCascade and produced non-null shapes. Full topology, mounting dimensions and physical fit are not certified by this import check.

## Current presentation — 2026-09-25

- `SYS/ADHERENT_Design_Review.pptx` supersedes the earlier snapshot. Ten slides retain the established design and cover used system interfaces.
- Removed camera/OCR, UPS, cellular and unapproved interior-lighting topic slides. Removed machine Wi-Fi/BLE/AP-mode options and payment-terminal interface alternatives from retained slide text, diagrams and notes.
- Site-network iPad access remains. CAN row control, RS485 IOCTRL, gantry controls, direct sensors, wired Ethernet and required status indication remain in scope. The status-light model remains TBC.
- NFC antenna is Molex 1462362151. Reader/front-end selection, host interface, RF matching and supply remain TBC; no specific host port is assigned.
- Presentation architecture reflects one SYSCTRL onboard 24 V-to-12 V SMPS and integrated power connectors. W04/W06/W07 are internal SYSCTRL links. Removed stale external cable totals and old document filenames.
- The overview image is a presentation-specific view of the current draw.io diagram with excluded blocks omitted. The source system diagram is unchanged.
- Final PPTX passed package/layout validation, a normal Microsoft PowerPoint opening, and visual review of all slides. README links now point to the current presentation.

## IOCTRL quantity change — 2026-09-25

- The Waveshare **ESP32-S3-ETH-8DI-8RO** IOCTRL module is used **twice per system**: IOCTRL-01 and IOCTRL-02. This supersedes every earlier "IOCTRL quantity 1" statement.
- System controller count: MAINCTRL ×1 and IOCTRL ×2 purchased (**3 purchased controller assemblies**), plus the custom boards.
- Open for the second module: assigned functions and I/O allocation, RS485 topology/addressing/termination, 24 V and 12 V feed branches (W34/W35, F17/F18), cabinet placement, and the updated power budget.
- Aligned to IOCTRL ×2 on 2026-09-25: `README.md`, `SYS/README.md`, `SYS/ADHERENT_Electrical_Tables.xlsx` (row IOCTRL-01, -02, qty 2), `SYS/ADHERENT_System_Wiring_Diagram.drawio` + PNG, `SYS/ADHERENT_Design_Review.pptx` (slides 3, 7, 10 and notes), `MEC/Board_STEP_Models/README.md` and `FW/README.md`.
- Diagram shows IOCTRL-01/-02 as one stacked block ("COTS ×2") because the I/O split is undefined; draw two separate blocks once the allocation is decided. The PNG was rendered with the draw.io viewer, not the desktop CLI; re-export from draw.io desktop if exact font rendering matters.
- The small overview image on presentation slide 3 is an earlier presentation-specific render and still shows one IOCTRL; its text is not legible at slide size. Regenerate it with the next diagram change.

## LANECTRL R1 documentation alignment — 2026-09-25

- The LANECTRL section above was rewritten from the current `HW_ADHERENT_LANECTRL_R1` SchDoc/PcbDoc files: TPS4H160 high-side drive, 24 V-only supply, single 4-pin Micro-Fit bus connector, 7 × 3-pin Micro-Fit lane connectors, C&K rocker switches, off-board lane LEDs, and a 504 × 60 mm 4-layer PCB. Superseded: H-bridge, 12 V lane logic, B3F-4055, WP7113ID and DRV8876.
- Recorded the critical +24V_PR / VM disconnection in `04_POWER` (fix before fabrication), the stale netlist/BOM/PDF outputs and the single-bus-connector harness decision.
- Aligned `README.md`, `FW/README.md`, `MEC/Board_STEP_Models/README.md`, the LANECTRL/CONVEYOR rows of `SYS/ADHERENT_Electrical_Tables.xlsx`, row 18 of `MEC/ADHERENT_Mechanical_BOM.xlsx`, the LANECTRL blocks in `SYS/ADHERENT_System_Wiring_Diagram.drawio` and the connector HOLD line of `SYS/ADHERENT_Design_Review.pptx`.
- Fixed the bracket DWG links; the file is in `MEC/01_CAD_MODELS/Drawıng/`.

## System diagram layout rebuild — 2026-09-25

- `SYS/ADHERENT_System_Wiring_Diagram.drawio` is now generated by `.work/gen_diagram.py` (fixed coordinates, orthogonal corridors). Edit the script and re-render, or edit the `.drawio` directly and keep the PNG in step.
- Layout: column 1 = network / AC + PSU1 / NFC; column 2 = control cabinet (MAINCTRL, SYSCTRL with BUCK12 and SYSCTRL-PWR, IOCTRL ×2, status light); column 3 = gantry / labeling / doors; column 4 = ten lane rows. IOCTRL is drawn inside the control cabinet, matching the parts sheet location.
- Content is unchanged: all W / F / J / K / RO / DI references, part numbers and TBC flags were carried over and checked by script. Wording was shortened; details that the connecting line already shows (for example W13, W15, W20 / W21, W23) moved from box text to the line labels.
- Added the missing custom PCB **NFC · HW_ADHERENT_NFC_R1** (STM32F103C8 + ST25R200 reader, CAN node, 24 V + CAN on a 4-pin Micro-Fit) in place of the "NFC reader / front end TBC" block. Its system wiring (CAN position / node ID, 24 V branch and fuse, mounting) has no W / F reference yet, so no harness is drawn. The parts sheet NFC row was updated to match.
- `HW_ADHERENT_LABELCTRL_R1` is an empty KiCad skeleton with no defined function, so it is not shown.
- PNG rendered with draw.io desktop 24.7.17 (CLI, scale 1.75).

## Harness wiring diagram and system diagram update — 2026-09-26

- New `SYS/ADHERENT_Harness_Wiring_Diagram.drawio` + PNG (generator `.work/gen_harness.py`, photos `.work/harness_img`), in the style of the user-supplied example (`SYS/ADHERENT_System_Wiring_Diagram_.drawio`, unchanged): device containers with product photos, connector.pin boxes, conductor-level wires, CAN bus drawn as two lines with drops, typical boxes for repeated devices (X / Z, sensors ×6, latches ×4, door sensors ×5, LANECTRL ×10, conveyors ×70).
- Build steps are draw.io layers: ① AC & PE, ② 24 V main feed, ③ cabinet DC branches, ④ CAN, ⑤ Ethernet & RS485, ⑥ X / Z drives, ⑦ labeling motors & servo, ⑧ sensors, ⑨ doors & latches, ⑩ lane rows (with row-chain inset), ⑪ status light & marker (TBC). Page 2 lists every cable instance with R27 length estimates; page 3 is the connector reference.
- Pin sources: LANECTRL R1 SchDoc / PcbDoc, NFC R1 and SYSCTRL R1 netlists, Mean Well RSP-500 spec (TB1 1 AC/L · 2 AC/N · 3 FG; TB2 1–3 −V · 4–6 +V; CN100 unused, RC open = on), FN9264 listing (C14, 2-pole switch, no fuse holder), MYIR page (12 V / 2 A jack, 1× CAN, 1× RS485), Waveshare wiki / product page (7–36 V, isolated RS485 with 120 Ω jumper NC by default, relays 1NO / 1NC, DI 5–36 V NPN / PNP), plus the motor / sensor / antenna sources listed in the Motors and NFC sections.
- Product photos were collected from the manufacturer / supplier pages (Mean Well, Schaffner/TE, MYIR, Waveshare, Emtech, McMaster, Miuzei, Omron, Molex, conveyor supplier sheet, NFC render from the repo). The McMaster 1422N13 page did not load; the J2 photo, the SYSCTRL render and the LANECTRL render come from the supplied example diagram and are captioned as such.
- The latch 0 V return is drawn as the 0 V conductor of W35 (R27: "relay COM and latch returns"). CAN terminations: MAINCTRL end and LANECTRL-01 (P1) only; RS485: jumper at the last IOCTRL. PE reaches PSU1 FG through the chassis stud (W37); R27 lists W01 as L/N/PE — settle in the bonding plan.
- Independent check (separate reviewer, 2026-09-26) confirmed all SYSCTRL / NFC / LANECTRL pin maps, PSU1 terminals, the 23MSD pinout, antenna, conveyor and R27 cable lengths; its corrections were applied (112 Ω termination wording, R27 branch IDs vs R1 board fuses, W34 quantity 1–2, conveyor SIG = +24 V via plate switch, W15 length TBC, W20 / W21 polarity by convention, LEDS pin 2 = GND confirmed).
- `SYS/ADHERENT_System_Wiring_Diagram.drawio` updated from the same checks: J1 text (2-pole switch, fuse / breaker TBC), BUCK12 = LM5146 12 A design, SYSCTRL interfaces (J11 / J13 / J12 / J14 / J15), ⚠ flags for the SYSCTRL output count, Emtech 48 V listing, CHUCK integrated driver, NFC antenna connector and the LANECTRL R1 rail error; CHUCK is no longer described as "4-wire"; NFC 24 V + CAN tap drawn dashed (TBC); lane boxes shortened with the common facts moved to the lane note; legend gained ⚠.

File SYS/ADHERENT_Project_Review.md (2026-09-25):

> Historical engineering review: workbook tab references and counts below describe commit `aef502b`. The current customer deliverable is [ADHERENT_Electrical_Tables.xlsx](ADHERENT_Electrical_Tables.xlsx), one worksheet. Use the current diagram for component references.

# Adherent R27 document review

## Subsequent SYSCTRL / NFC correction

Electrical tables and component register now reflect the merged SYSCTRL power-connector area. W04/W06/W07 are internal functions with zero external cable quantity. DIST24/DIST12 are included SYSCTRL functions, not separate modules; the 17-DIN-holder purchase assumption is withdrawn. F1-F18 remain 18 logical branch references with implementation pending. The presentation validation below refers to the earlier review snapshot, not these subsequent changes.

Selected NFC antenna: Molex 1462362151, planning quantity one. Manufacturer data: 13.56 MHz, 15 x 15 x 0.27 mm, adhesive mount, 102 mm cable and 2.40 uH. Reader/front-end, matching, host interface and supply remain open under O16. No complete reader or payment terminal is selected.

Current schedules: 39 stable W identifiers, 28 required external cable types, 123 grouped external harness runs/assemblies and five unresolved route lengths. Known route allowance subtotal is 109.5 m. Reader host/power harnesses are not yet defined and are additional to this subtotal. The component register contains 82 rows.

Power checks preserve the 268.96 W known subtotal, while explicitly flagging four unresolved load-current entries including the NFC reader; marker power is also unresolved. Tests cover a second peak conveyor (+48 W), zero SMPS efficiency and a concurrency count above installed quantity. Invalid cases produce a HOLD status rather than a capacity approval. No formula error cells were found in the exported workbooks.

## Original review scope and findings

Reviewed against the current system diagram, supplied mechanical BOM and conveyor sheet, recorded project decisions and supplier references in the workbooks. This is a document and architecture review; no physical machine, manufactured PCB or bracket-fit test was performed.

## Changes completed

- Aligned presentation, electrical workbook and draw.io to one 24 V system PSU and SYSCTRL-derived 12 V. RSP-500-24 rating: 24 V, 21 A, 504 W.
- Removed junction boxes. W15 is six direct SYSCTRL sensor runs; W23 is five direct IOCTRL sensor runs. W14/W22 are retired with zero quantity.
- Separated IOCTRL's 24 V module feed W34 from its 12 V latch-contact feed W35. Relay contacts do not generate 12 V.
- Added the requested component/part-number spreadsheet: 74 rows including diagram components, internal parts, interface positions and excluded/external items. Unknown MPNs are TBC.
- Included McMaster 1422N13 J2, one per machine, in both BOMs and the component register. Retained native COTS connectors separately from custom-board Micro-Fit candidates.
- Corrected stale supply, driver and connector assumptions, obsolete naming in embedded presentation diagrams, and lane indexing. Replaced false completed-status icons with explicit open/excluded states.
- Retained 70 conveyors, 70 buttons, 70 LEDs, 10 LANECTRL assemblies and one each of MAINCTRL, SYSCTRL and IOCTRL. Two custom designs, eleven custom assemblies.
- Added status-light, protective-earth and marker-supply cable requirements. Corrected unrelated FW/SW template descriptions and model-availability documentation.

## Engineering evidence still required

The electrical workbook records O01-O15 with responsible roles and required evidence. Release blockers include exact gantry drive/brake compatibility at 24 V, SYSCTRL converter selection, conveyor loaded/stall current and signal reference, enforced concurrency, motor transient protection, harness/protection sizing and physical validation.

The candidate SMBJ33CA clamp specification does not establish protection below the candidate DRV8876 absolute maximum. A 6.3 A nominal fuse holder cannot be assumed suitable for a larger buck-input branch. Motor phase-current ratings do not substitute for drive supply-input current. Candidate parts remain unreleased.

Marker and latch/sensor models, MYIR order code, servo variant, PCB layouts and direct-harness lengths remain unresolved. The supplied bracket DWG is preserved, but PCB/button/LED fit has not been checked. Reconstructed STEP models do not validate real hardware dimensions.

## Verification

- Visually checked all 14 slides. Presentation package and layout validators reported no findings; three intentional template background shapes extend beyond slide boundaries.
- Rendered and inspected diagram and workbook content. Mapped all 44 component blocks in the diagram to spreadsheet entries. Checked edge references, direct sensor endpoints, cable IDs and quantities across spreadsheets.
- Recalculated power: known peak subtotal 268.96 W, excluding three unknown load currents and unresolved marker supply. Increasing peak conveyor concurrency from one to two adds 48 W, producing 316.96 W; restored baseline afterward. These are planning assumptions, not measured approval.
- Seven simultaneous 2 A conveyors plus row losses require 14.05 A, exceeding the candidate 5 A row fuse. Workbook flags this case.
- 39 stable cable identifiers; 31 required types. Five required route lengths missing. The 111 m known routing subtotal is not a complete cut list.
- 18 branch-protection positions: 17 DIN and F14 on SYSCTRL. Cached spreadsheet formulas contain no error cells.

Documents are aligned for design discussion and selection work. Manufacturing/procurement release remains pending the evidence above.

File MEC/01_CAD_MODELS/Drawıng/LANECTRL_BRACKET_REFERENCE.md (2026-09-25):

# LANECTRL front metal bracket

Mechanical reference: [LANE DRAWING SPACE FOR UMIT.DWG](LANE%20DRAWING%20SPACE%20FOR%20UMIT.DWG).

The user confirmed that the metal bracket in front of the LANECTRL board is being made to this drawing. Use this drawing as the reference for bracket and board mechanical integration.

Board folder: `HW/HW_ADHERENT_LANECTRL_R1`.

The drawing has been stored as supplied. Dimensions, clearances and PCB fit have not yet been checked against it.

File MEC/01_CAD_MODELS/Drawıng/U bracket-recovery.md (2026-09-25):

# U bracket CAD recovery

The local `U bracket.SLDPRT` is only a Git LFS pointer, not the CAD model.
The original repository returned HTTP 404 for its object during migration.
The pointer remains local and ignored so it does not prevent GitHub pushes.

Original object SHA-256: `521714e37d3652d6d5e93c6112689d84c9054d6c8f65e505774f4a12ce420c95`

Expected size: 176036 bytes.

Restore the actual model from a backup or its author, remove its `.gitignore`
entry, and commit the recovered file.

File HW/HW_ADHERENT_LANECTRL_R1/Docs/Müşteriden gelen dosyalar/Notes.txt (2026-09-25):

Layout burada paylaşılan dwg üzerinde olacak.
7 tane lane motor var, datasheeti yüklendi.
Pcb nin bottom tarafinda rocker switch ve led olacak, bottom tarafi işlemci, pwm surucu, programmer, usb, canbus, microfit connector içerecek.
Yani 7 tane lane motor u canbus uzerinden kontrol eden kart yapacağız.
Motor Ümit beyin elinde , kritik ve önemli sorular sorulacak.
Altium ile ilerliyoruz.
Bir medical firma.

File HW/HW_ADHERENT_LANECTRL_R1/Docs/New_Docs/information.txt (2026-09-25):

1- 24 volt  1.5 amper test altında, 190 ma.
2-Manuel olarak zorluyorum 280mA.
3-Baya baya zorluyorum 310mA, ikinci zorlamada 0.5Amper çekiyor. Elle durdurduk neredeyse 0.5 amper
Plaka var sensorun diğer ucunda bu açılıp kapanınca 0 volt ve 24 volt alıyoruz.
Plaka yalnızca pin 3'teki sinyali değiştirir; o sinyali okuyup motoru durdurmak bizim yapacağımız kartın işi.
Signal 24V dry contact

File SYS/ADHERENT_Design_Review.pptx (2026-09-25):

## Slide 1

BLACKOCEAN TECHNOLOGIES

Adherent Electrical Design Review

System interfaces and mechanical integration

Prepared for Adherent360
Automated Pharmaceutical Dispensing Unit
Current system architecture, 25 September 2026

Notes: Project sources: SYS/ADHERENT_System_Wiring_Diagram.drawio; SYS/ADHERENT_Electrical_Tables.xlsx; brain.md. Current architecture: PSU1 24 V, SYSCTRL integrated 12 V SMPS and power connectors, CAN row control and RS485 to two IOCTRL modules. Unresolved interfaces retain TBC.

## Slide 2

System interfaces

One 24 V PSU, SYSCTRL power conversion, CAN row control, RS485 door I/O and wired site Ethernet.

Gantry drives and sensors

SYSCTRL power conversion

1

2

CAN row controllers

3

Ethernet panel connection

4

RS485 door controller

5

Status indicator

6

iPad site-network access

7

Direct wiring and harnesses

8

NFC antenna and reader

Blackocean Technologies · Adherent360 APDU · Design review · 25 Sep 2026

9

Connector selection

10

2

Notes: Project sources: SYS/ADHERENT_System_Wiring_Diagram.drawio; SYS/ADHERENT_Electrical_Tables.xlsx; brain.md. Current architecture: PSU1 24 V, SYSCTRL integrated 12 V SMPS and power connectors, CAN row control and RS485 to two IOCTRL modules. Unresolved interfaces retain TBC.

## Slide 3

System architecture

70

conveyor lanes
10 rows × 7

2

custom boards
SYSCTRL · LANECTRL ×10

3

COTS controllers
MAINCTRL · IOCTRL ×2

1

24 V system PSU
12 V generated on SYSCTRL

MAINCTRL ×1 and IOCTRL ×2 are COTS. SYSCTRL ×1 and LANECTRL ×10 are custom assemblies. Each lane row has seven motors, buttons and LEDs.

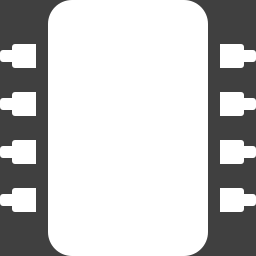
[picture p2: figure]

Boards

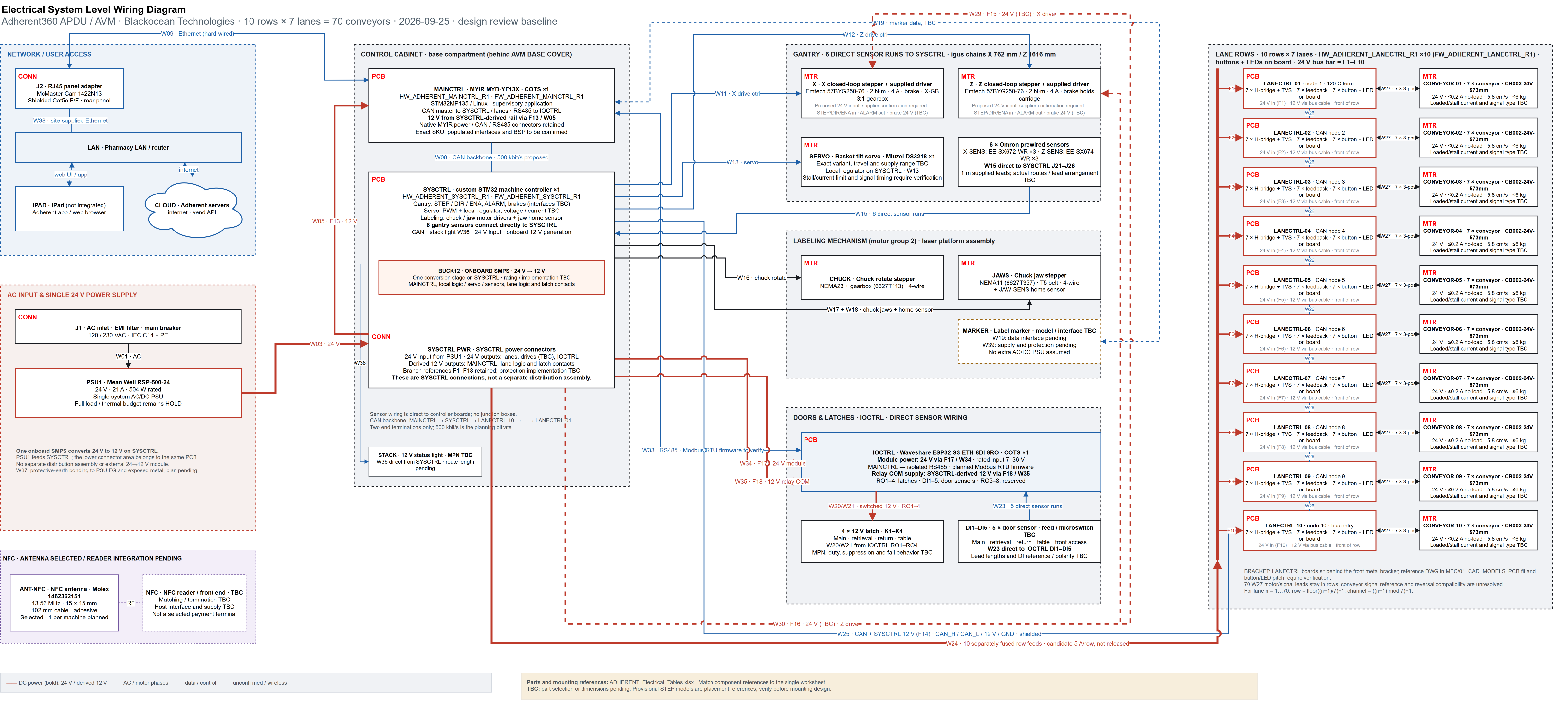
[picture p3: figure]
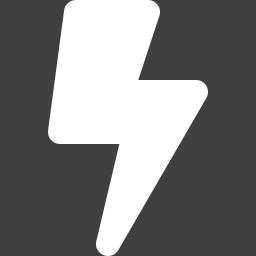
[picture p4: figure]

Power

PSU1 feeds SYSCTRL at 24 V. One onboard SMPS creates 12 V. Power distribution and connectors are part of SYSCTRL.

Comms

CAN links MAINCTRL, SYSCTRL and the ten LANECTRL boards. RS485 links MAINCTRL and both IOCTRL modules. Ethernet connects the site network.

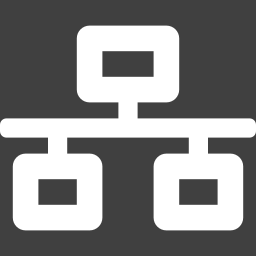
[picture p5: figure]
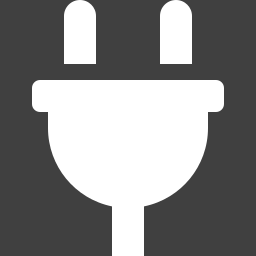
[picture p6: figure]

Connectors

Micro-Fit candidates on custom boards; native COTS connectors retained. Sensors run directly to controller boards.

ADHERENT_System_Wiring_Diagram.drawio and ADHERENT_Electrical_Tables.xlsx

Lane conveyor CB002-24V-573mm: 24 V, ≤ 0.2 A idle, 5.8 cm/s, ≤ 6 kg — 70 of them, one LANECTRL per row of 7.

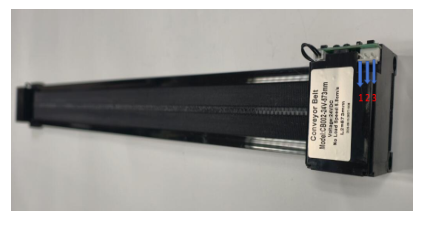
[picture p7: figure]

Blackocean Technologies · Adherent360 APDU · Design review · 25 Sep 2026

3

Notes: Project sources: SYS/ADHERENT_System_Wiring_Diagram.drawio; SYS/ADHERENT_Electrical_Tables.xlsx; brain.md. Current architecture: PSU1 24 V, SYSCTRL integrated 12 V SMPS and power connectors, CAN row control and RS485 to two IOCTRL modules. Unresolved interfaces retain TBC.

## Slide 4

TOPIC 1 OF 6

Gantry drives from the mechanical BOM

ENGINEERING CHECKS

1. Provide the exact motor, driver and brake datasheets.
2. Can the supplied driver meet the motion load at 24 V?
3. What are the STEP/DIR, ALARM and brake interfaces?
4. Can the sensor leads reach SYSCTRL directly?

HOLD O01/O15: W11, W12, W15, W29, W30 and the full PSU budget.

PSU1 · 24 V system rail (drive use TBC)

X / Z motors + supplied drivers
Brakes; X has 3:1 gearbox

SYSCTRL
Control + alarms
Brake interface TBC

6 sensors → SYSCTRL directly (W15)

Single 24 V architecture; exact drive compatibility and brake interface remain open.

- Two Emtech 57BYG250-76 motors include supplied drivers and brakes. X uses a 3:1 gearbox.
- Verify 24 V operation, driver input current, control levels and brake requirements.
- Six gantry sensors connect directly to SYSCTRL. Confirm lead lengths and chain routing.

Blackocean Technologies · Adherent360 APDU · Design review · 25 Sep 2026

4

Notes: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

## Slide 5

TOPIC 2 OF 6

Ethernet panel connection

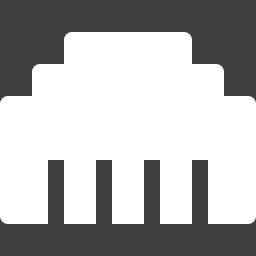
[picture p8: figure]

INTEGRATION CHECKS

1. Confirm rear-panel placement and service access.
2. Agree DHCP or static addressing with site IT.
3. Confirm VLAN, firewall and server access requirements.

J2 is selected in both BOMs. W09 is internal; W38 is the site-supplied cable.

MAINCTRL
Native Ethernet port

J2 · McMaster
1422N13
Shielded Cat5e F/F

Site LAN
IT policy TBC

W09 internal patch · W38 external site cable · no internal switch

J2 selected: McMaster-Carr 1422N13, quantity 1 per machine.

- J2 is the McMaster 1422N13 shielded Cat5e RJ45 female/female panel adapter.
- Check its 24.13 mm panel cutout, fasteners and cable bend clearance.
- W09 connects MAINCTRL to J2. W38 connects J2 to the site network.

Blackocean Technologies · Adherent360 APDU · Design review · 25 Sep 2026

5

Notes: Project sources: SYS/ADHERENT_System_Wiring_Diagram.drawio; SYS/ADHERENT_Electrical_Tables.xlsx; brain.md. Current architecture: PSU1 24 V, SYSCTRL integrated 12 V SMPS and power connectors, CAN row control and RS485 to two IOCTRL modules. Unresolved interfaces retain TBC. Ethernet adapter: https://www.mcmaster.com/product/1422N13

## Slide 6

TOPIC 3 OF 6

iPad access through the site network

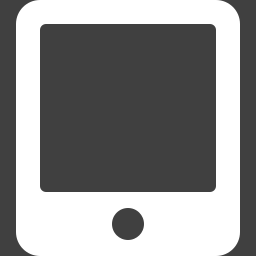
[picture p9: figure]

INTEGRATION CHECKS

1. Confirm application and server endpoints.
2. Define machine selection and account permissions.
3. Agree authentication ownership and session handling.

Application behavior remains to be implemented and tested.

External iPad
Adherent app / browser

Site network

J2 / MAINCTRL
Wired Ethernet

Adherent application / server endpoints TBC

The external iPad uses the Adherent app or browser on the site network.

- MAINCTRL connects to the site network through J2.
- The external iPad accesses the Adherent application through that network.
- Authentication and device-to-machine association remain to be defined.

Blackocean Technologies · Adherent360 APDU · Design review · 25 Sep 2026

6

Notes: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

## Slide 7

TOPIC 4 OF 6

Wire harness drawings

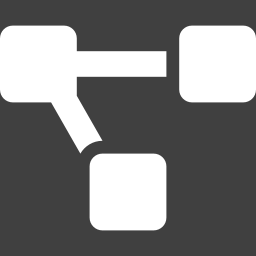
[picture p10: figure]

ENGINEERING CHECKS

1. Measure direct sensor routes and check the supplied 1 m leads.
2. Confirm chain fill, bend radius and service loops.
3. Verify LANECTRL placement against the bracket DWG.
4. Release one pin-to-pin drawing per required harness.

HOLD O06/O12/O15: no blanket 22 AWG or parallel-pin current rating.

SYSCTRL
J21–J26

6 gantry sensors
W15 direct; route lengths TBC

IOCTRL ×2
DI1–DI5

5 door sensors
W23 direct; route lengths TBC

LANECTRL ×10

70 conveyor leads W27
Bracket fit / signal pin check TBC

Sensors connect directly to SYSCTRL and IOCTRL; no junction boxes.

- W15 carries six direct gantry sensor runs to SYSCTRL. W23 carries five direct door sensor runs to IOCTRL; split across the two modules TBC.
- W04, W06 and W07 are internal SYSCTRL connections.
- Finalize external harness routes, conductor sizes, mating connectors and service loops.

Blackocean Technologies · Adherent360 APDU · Design review · 25 Sep 2026

7

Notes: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

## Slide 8

TOPIC 5 OF 6

NFC antenna and reader

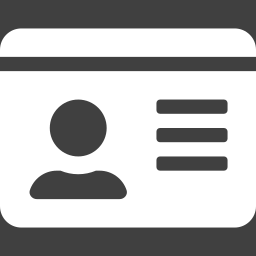
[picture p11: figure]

INTEGRATION CHECKS

1. Confirm the reading position and surrounding metal.
2. Select a compatible reader/front-end.
3. Define RF termination, host interface and power.
4. Validate reading range in the final enclosure.

Antenna selected. Reader integration and mounting remain open.

ANT-NFC
Molex 1462362151
15 × 15 mm, 102 mm cable

NFC reader / front end
Selection pending
RF matching / supply TBC

Host interface and board allocation TBC

Selected antenna: Molex 1462362151, one per machine.

- ANT-NFC is Molex 1462362151: 13.56 MHz, 15 × 15 × 0.27 mm, adhesive mounting and 102 mm cable.
- The NFC reader/front-end remains to be selected.
- Host interface, supply voltage and RF matching remain unassigned.

Blackocean Technologies · Adherent360 APDU · Design review · 25 Sep 2026

8

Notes: Project sources: SYS/ADHERENT_System_Wiring_Diagram.drawio; SYS/ADHERENT_Electrical_Tables.xlsx; brain.md. Current architecture: PSU1 24 V, SYSCTRL integrated 12 V SMPS and power connectors, CAN row control and RS485 to two IOCTRL modules. Unresolved interfaces retain TBC. NFC source: https://www.molex.com/en-us/products/part-detail/1462362151 and https://www.digikey.com/en/products/detail/molex/1462362151/15204370

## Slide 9

TOPIC 6 OF 6

Connector standard

ENGINEERING CHECKS

1. Approve exact mating housings, contacts and keying.
2. Validate gauge, temperature rise and voltage drop.
3. Confirm service access and panel cutouts.
4. Do not treat a generic per-pin rating as harness approval.

HOLD O03/O05/O06: conveyor feedback, high-side switch/TVS coordination and protection.

CUSTOM BOARDS
Match PCB connector MPNs
Verify mates and current limits

COTS BOARDS
Native MYIR / Waveshare connectors
Verify pinouts

PANEL / POWER
J2: 1422N13
Mains / protection selection pending

Connector families are candidates until mating and current checks are complete.

- Custom PCB connector selections must match their actual schematics and mating harnesses.
- MYIR and Waveshare boards retain their native connectors. J2 is McMaster 1422N13.
- SYSCTRL contains its power routing and connectors. Verify ratings, pinouts and mounting access.

Blackocean Technologies · Adherent360 APDU · Design review · 25 Sep 2026

9

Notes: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

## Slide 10

Remaining integration work

OPEN

Gantry drives

OPEN

SYSCTRL power

24 V compatibility and brake/control levels

Onboard SMPS sizing and branch protection

OPEN

CAN network

Termination and backbone wiring validation

OPEN

Ethernet

J2: 1422N13. Site IT policy pending

OPEN

RS485 door I/O

OPEN

Status indicator

IOCTRL ×2: addressing, I/O split, pinouts

Select STACK model and confirm W36 route

OPEN

iPad access

Site network and application authentication

OPEN

Harnesses

Direct sensor runs, route lengths and fit

OPEN

NFC

OPEN

Connectors

1462362151 selected. Reader interface TBC

Exact mates, conductor sizes and ratings

Open items: drive data, converter sizing, protection, harness validation and NFC reader selection.

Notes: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

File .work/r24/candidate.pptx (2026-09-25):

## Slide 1

BLACKOCEAN TECHNOLOGIES

APDU Electrical Design Review

Open questions to close before schematics start

Prepared for Adherent360
Automated Pharmaceutical Dispensing Unit (AVM)
Baseline: Electrical System Level Wiring Diagram R24 · 14 September 2026

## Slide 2

Review topics and meeting decisions

Already closed: no E-stop (vending machine) · table-door actuator out of scope · MAINCTRL and IOCTRL are off-the-shelf boards.

Gantry drives from the mechanical BOM

Camera and OCR: needed?


1

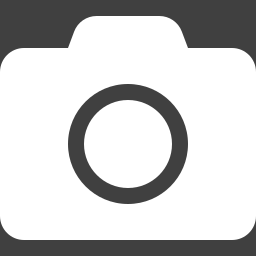
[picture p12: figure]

2

UPS / battery: not approved

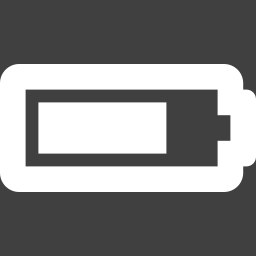
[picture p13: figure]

3

Ethernet port location


4

Cellular: not approved

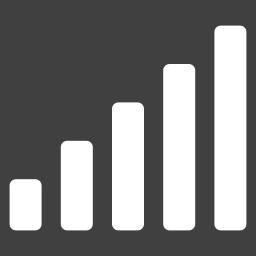
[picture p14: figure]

5

Product illumination

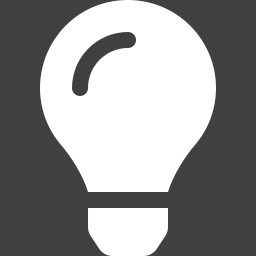
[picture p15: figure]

6

iPad connection: QR, Wi-Fi or BLE

7

Wire harness drawings

8


NFC and card reader

Blackocean Technologies · Adherent360 APDU · Design review · 14 Sep 2026


9

Connector standard


10

2

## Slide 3

Architecture baseline (R24)

70

conveyor lanes
10 rows × 7

2

custom boards
SYSCTRL · LANECTRL ×10

2

COTS controllers
MAINCTRL · IOCTRL

34

cables W01–W34
≈ 125 m

MAINCTRL = COTS MYIR MYD-YF13X (STM32MP135, Linux) · SYSCTRL custom STM32 (gantry + labeling) · IOCTRL = COTS relay / IO module on RS485 · LANECTRL ×10 custom, our design, with the lane buttons and LEDs on the board.


Boards

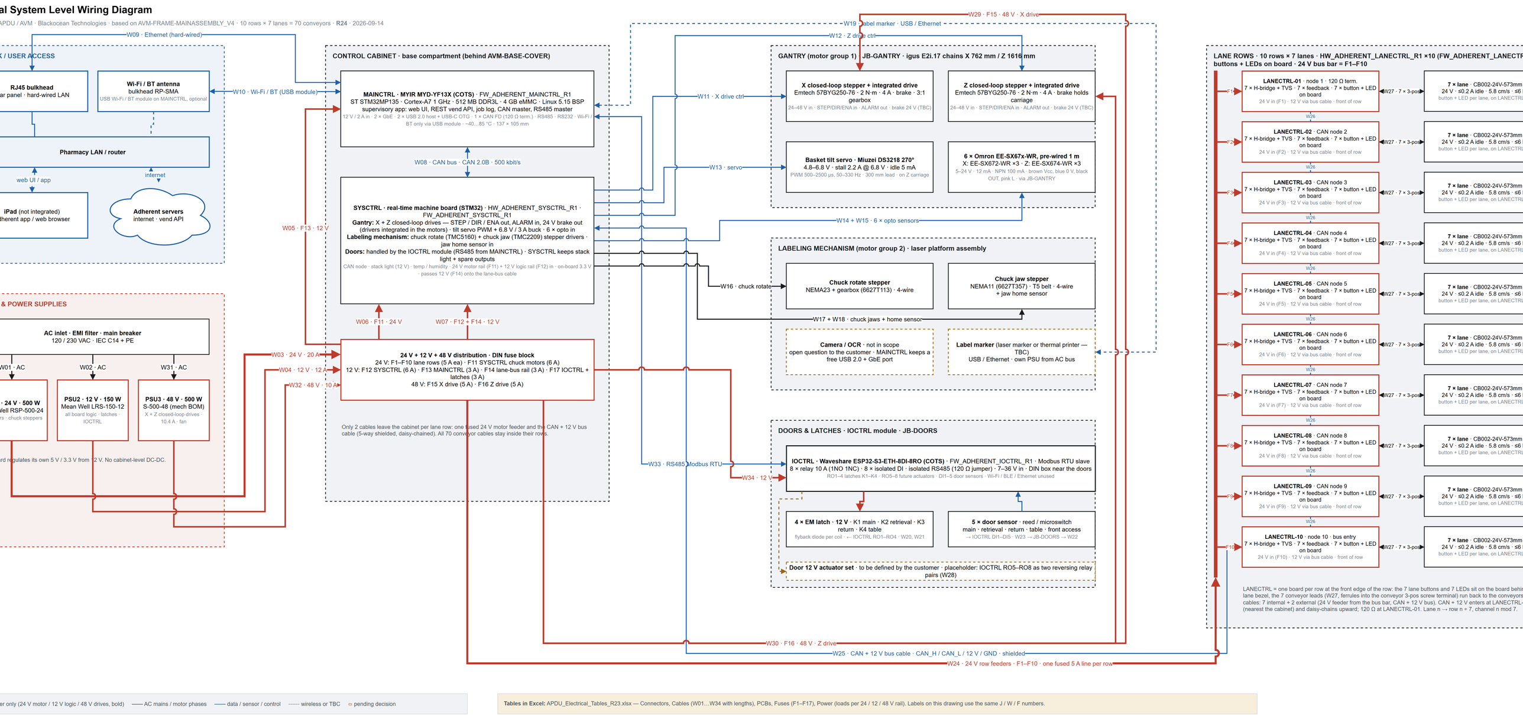
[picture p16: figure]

Electrical System Level Wiring Diagram R24 (full drawing in draw.io; tables in APDU_Electrical_Tables_R23.xlsx)

Lane conveyor CB002-24V-573mm: 24 V, ≤ 0.2 A idle, 5.8 cm/s, ≤ 6 kg — 70 of them, one LANECTRL per row of 7.

Power

24 V motor rail · 12 V logic rail for every board · 48 V for the gantry drives · DIN fuses F1–F17.

Comms

CAN backbone to SYSCTRL and the 10 lane rows · RS485 to IOCTRL · Ethernet / Wi-Fi to the site.


Connectors

Micro-Fit 3.0 on every PCB · one standard 4c 22 AWG cable · every cable named and listed.


Blackocean Technologies · Adherent360 APDU · Design review · 14 Sep 2026

3

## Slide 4

TOPIC 1 OF 10

Gantry drives from the mechanical BOM

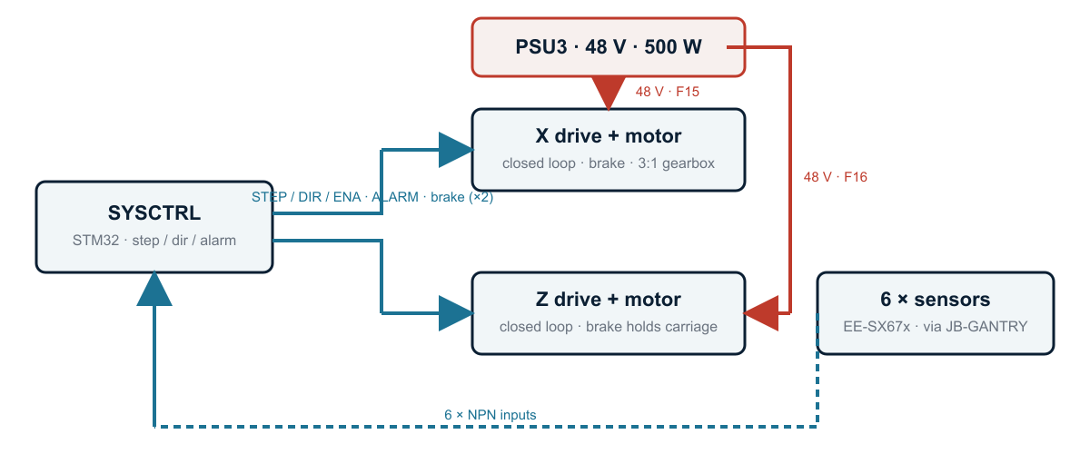
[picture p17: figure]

48 V drive units with brake and driver built in; SYSCTRL sends step / direction and reads alarms.

- Emtech 57BYG250-76 closed-loop steppers, 2 N·m / 4 A, brake and driver integrated; X with a 3:1 gearbox.
- New 48 V / 500 W supply (PSU3) for the two drive units; SYSCTRL keeps only STEP / DIR / ENA, ALARM and the brake outputs.
- 6 Omron EE-SX67x sensors with 1 m leads meet in JB-GANTRY; chains X 762 mm, Z 1616 mm.

Blackocean Technologies · Adherent360 APDU · Design review · 14 Sep 2026

QUESTIONS FOR ADHERENT360

1. Drive datasheet: STEP / DIR signal level, ALARM output, who controls the brake?
2. Is 48 V really needed, or would the 24 V rail do?
3. Generic drive acceptable, or a documented equivalent (Leadshine class)?
4. Labeling-mechanism BOM: when, and integrated drives there too?

Affects: PSU count, SYSCTRL I/O, connectors J16 / J17, cables W11, W12, W29, W30.

4

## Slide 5

TOPIC 2 OF 10

Camera and OCR: is it needed?

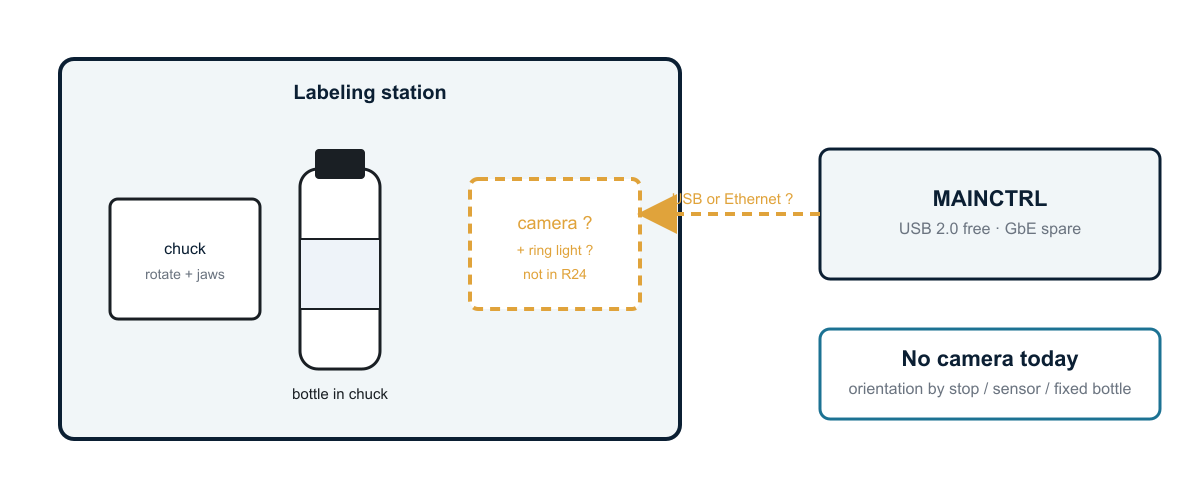
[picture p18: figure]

Taken out of the R24 baseline; the labeling station keeps the space and the ports for it.

- R24 has no camera, no ring light and no camera cable; nothing from the customer defines one yet.
- MAINCTRL keeps a free USB 2.0 port and a spare Gigabit port, so a camera can be added later without a board change.
- Without a camera the chuck needs another reference to orient the bottle for marking: a mechanical stop, a sensor, or one fixed bottle type.

Blackocean Technologies · Adherent360 APDU · Design review · 14 Sep 2026

QUESTIONS FOR ADHERENT360

1. Is a camera needed at all: bottle orientation for marking, dispense verification, or an audit photo?
2. If yes: read text (OCR), or only find a mark or the label edge?
3. USB or Ethernet camera, and where does it mount: labeling station or retrieval bay?
4. Are images stored? Labels carry patient data, so retention and encryption rules apply.

Affects: MAINCTRL software scope, ring light and 24 V budget, one cable, labeling-station bracket.

5

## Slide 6

TOPIC 3 OF 10

UPS and battery backup

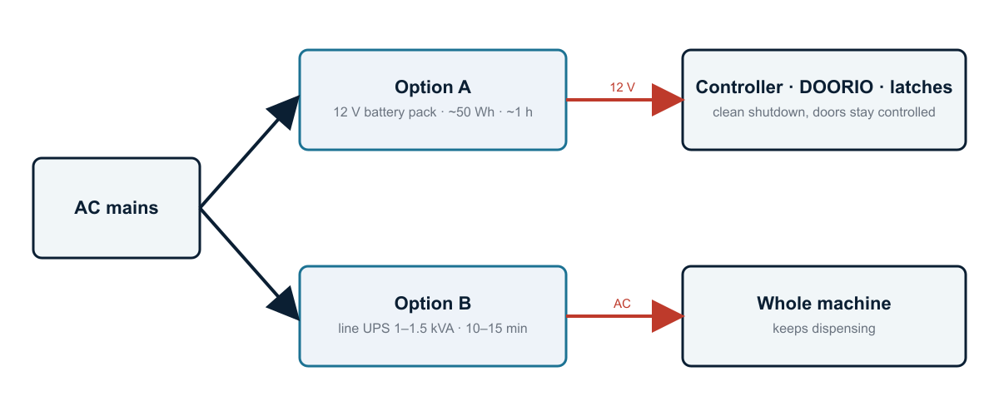
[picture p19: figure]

Rejected alternatives, retained only as a meeting record.

- The customer rejected UPS and battery backup during the meeting.
- The customer considers backup power unnecessary.
- The system uses the existing AC-fed power supplies.

Blackocean Technologies · Adherent360 APDU · Design review · 14 Sep 2026

MEETING DECISION

1. Not approved during the meeting.
2. UPS and battery backup are not required.
3. Excluded from the electrical design.

Closed: no UPS or backup battery in the R24 drawing.

6

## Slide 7

TOPIC 4 OF 10

Ethernet port location

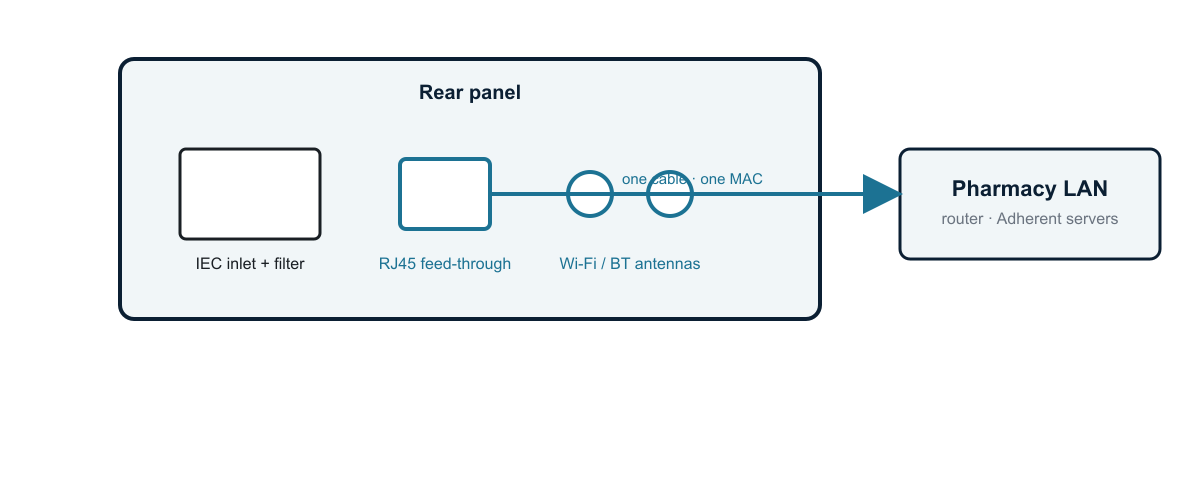
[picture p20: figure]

Rear panel as drawn in R24: one RJ45 feed-through, no switch inside the cabinet.

- One RJ45 feed-through on the rear panel beside the AC inlet; Wi-Fi (USB module on MAINCTRL) is the backup path.
- MAINCTRL has two Gigabit ports on board: one to the site, one spare for an Ethernet label marker. No switch in the cabinet.
- One external port means one cable and one MAC address on the pharmacy network.

Blackocean Technologies · Adherent360 APDU · Design review · 14 Sep 2026

QUESTIONS FOR ADHERENT360

1. Rear, side or bottom for the port, and how close to the wall does the unit stand?
2. Static IP or DHCP; any VLAN or firewall rules?
3. Is the label marker Ethernet or USB?
4. Is Wi-Fi acceptable as the only link at some sites?

Affects: rear-panel cut-outs, cabinet BOM, IT onboarding sheet.

7

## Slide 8

TOPIC 5 OF 10

Cellular (LTE) modem

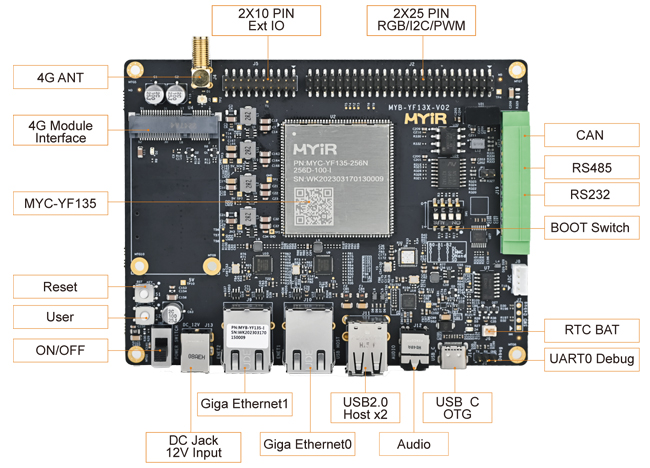
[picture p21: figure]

MYIR MYD-YF13X MAINCTRL board. Cellular hardware will not be fitted.

- The customer rejected cellular connectivity during the meeting.
- The site network carries the vend API and remote service.
- No cellular modem, SIM, data plan or LTE antennas are included.

Blackocean Technologies · Adherent360 APDU · Design review · 14 Sep 2026

MEETING DECISION

1. Not approved during the meeting.
2. Cellular connectivity is not required.
3. Excluded from the electrical design.

Closed: no cellular connection in the R24 drawing.

8

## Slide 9

TOPIC 6 OF 10

Product illumination

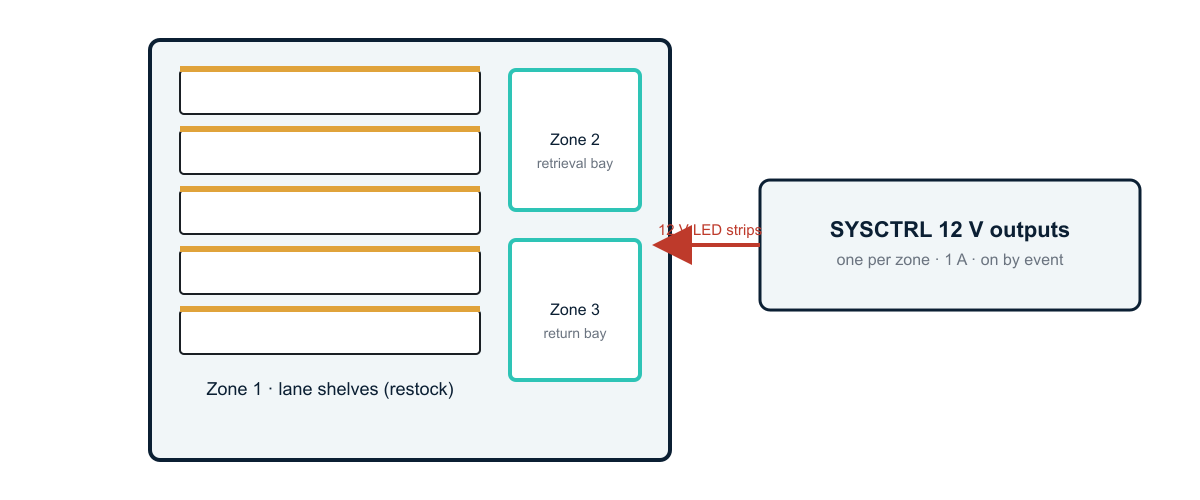
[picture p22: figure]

Three candidate zones, each on its own 12 V output.

- No lighting in the R24 baseline.
- Proposal: 12 V LED strips per zone driven by SYSCTRL outputs — lane shelves, retrieval bay, return bay — switched on by events.
- Same Micro-Fit connectors; about 1 A of 12 V per zone.

Blackocean Technologies · Adherent360 APDU · Design review · 14 Sep 2026

QUESTIONS FOR ADHERENT360

1. Which zones need light?
2. For the customer through a window, or for staff during restocking?
3. Always on, or only on events?
4. Neutral white, or a status colour at the retrieval bay?

Affects: SYSCTRL outputs, 12 V budget, row harness routing.

9

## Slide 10

TOPIC 7 OF 10

iPad connection: QR code, Wi-Fi or BLE

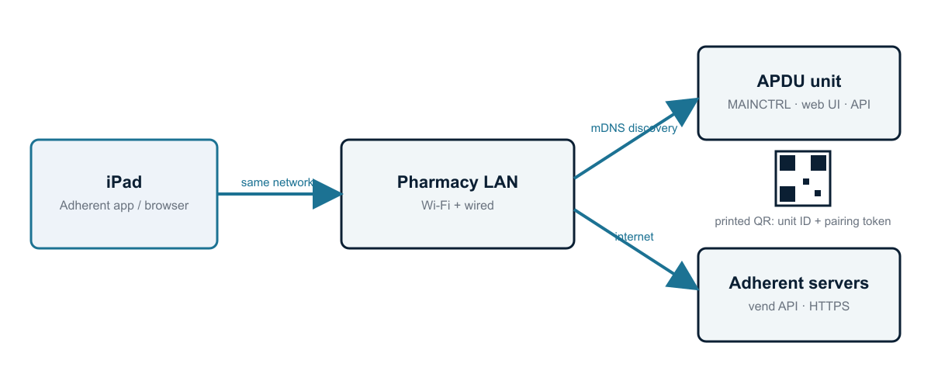
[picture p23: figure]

Recommended flow: same LAN, mDNS discovery, printed QR code for first pairing.

- The iPad talks to the unit over the pharmacy LAN; the unit talks to the Adherent servers.
- Recommended: mDNS discovery plus a printed QR code (unit ID and pairing token). No extra hardware.
- BLE only if proximity pairing is wanted; it needs the optional USB Wi-Fi / BT module, the board has no radio on board.

Blackocean Technologies · Adherent360 APDU · Design review · 14 Sep 2026

QUESTIONS FOR ADHERENT360

1. Will the iPad be on the pharmacy Wi-Fi, or must it work without the site network?
2. Printed QR code acceptable, or a dynamic code on the unit?
3. How many units per pharmacy?
4. Who owns authentication: the Adherent cloud or a local login?

Affects: MAINCTRL software scope, cabinet label, antenna placement.

10

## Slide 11

TOPIC 8 OF 10

Wire harness drawings

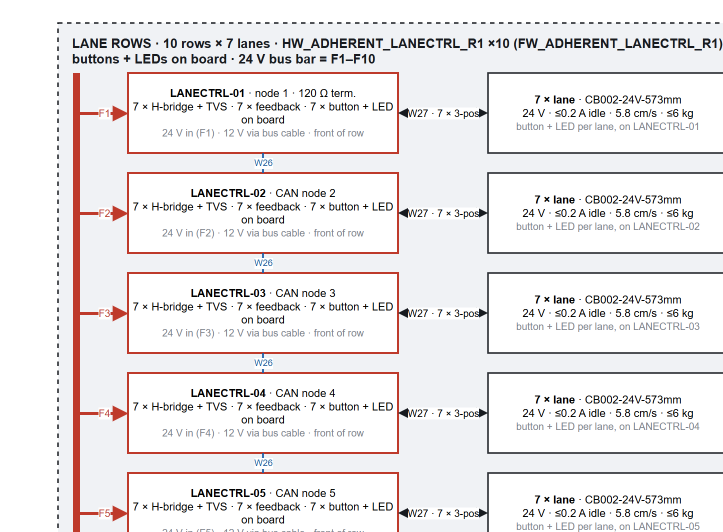
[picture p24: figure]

Lane rows in R24: every cable already carries its W number and appears in the cable list.

- Next deliverable: one drawing per cable, W01–W34, derived from the R24 diagram and the cable list.
- Lengths estimated from the CAD envelope (855 × 890 × 1905 mm): about 125 m in total, 146 m of the standard 4c 22 AWG cable.
- Routing paths and chain fill are needed from the mechanical team before lengths are final.

Blackocean Technologies · Adherent360 APDU · Design review · 14 Sep 2026

QUESTIONS FOR ADHERENT360

1. Can we get the cable routing paths and the chain inner sizes?
2. Service loops or blind-mate connectors on the drawer rows?
3. Who builds the harnesses: us, a harness shop, or the integrator?
4. Any existing colour or labelling convention?

Affects: harness drawing effort, connector counts, BOM v1 timing.

11

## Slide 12

TOPIC 9 OF 10

NFC and card reader

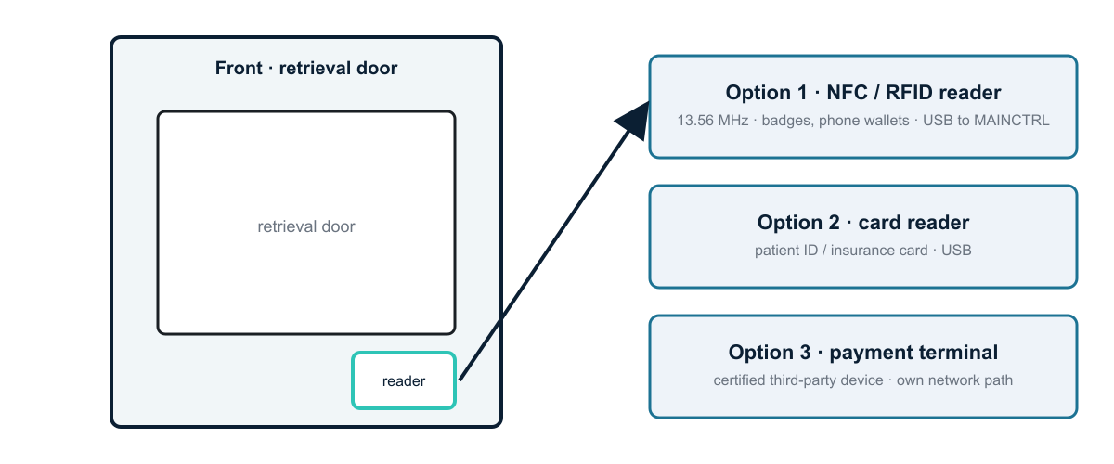
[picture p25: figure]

Not in R24 yet; the cut-out and cable can be planned now.

- Natural place: front panel next to the retrieval door, USB to MAINCTRL.
- NFC / RFID reader: small cost and one USB port. Payment terminal: a certified third-party device.
- Plan the panel cut-out and cable now even if the reader comes later.

Blackocean Technologies · Adherent360 APDU · Design review · 14 Sep 2026

QUESTIONS FOR ADHERENT360

1. Use case: staff login, patient pickup, or payment?
2. Which card: badge, patient ID, insurance, credit, phone wallet?
3. Where should the reader sit?
4. Validated in the Adherent cloud, or locally?

Affects: MAINCTRL USB ports, front-panel cut-out, security scope.

12

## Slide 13

TOPIC 10 OF 10

Connector standard


Micro-Fit 3.0 parts used on every board (illustration).

- Every PCB input and output: Molex Micro-Fit 3.0, 3 mm pitch, 5 A per pin, one crimp tool.
- Panel: Schaffner IEC inlet, Neutrik RJ45, RP-SMA; DIN fuse terminals. Conveyor side: its own 3-position screw terminal.
- Lane buttons and LEDs sit on the LANECTRL board itself, no extra harness; junction boxes use ferrules and WAGO 221.

Blackocean Technologies · Adherent360 APDU · Design review · 14 Sep 2026

QUESTIONS FOR ADHERENT360

1. Approved connector vendor list to follow?
2. Tool-less field replacement of a LANECTRL or a conveyor expected?
3. IP rating for the front bays?
4. Keyed or colour-coded housings so rows cannot be cross-plugged?

Affects: BOM v1 connector lines, LANECTRL layout, service documentation.

13

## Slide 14

Meeting decisions and remaining questions

Gantry drives

Camera / OCR

48 V confirmed · drive interface · datasheet

needed at all · purpose · USB vs Ethernet

Backup power

Not approved in the meeting. Not required.

Network

port location · IP policy

Cellular

Lighting

Not approved in the meeting. Not required.

zones · event-driven vs always on · colour

iPad pairing

LAN + QR (recommended) vs AP mode vs BLE

Harnesses

routing paths from mechanical · who builds

NFC / card

Connectors

use case · card type · location

vendor list · tool-less service · IP rating

R24 removes cellular and backup power. The remaining questions stay open for the team.

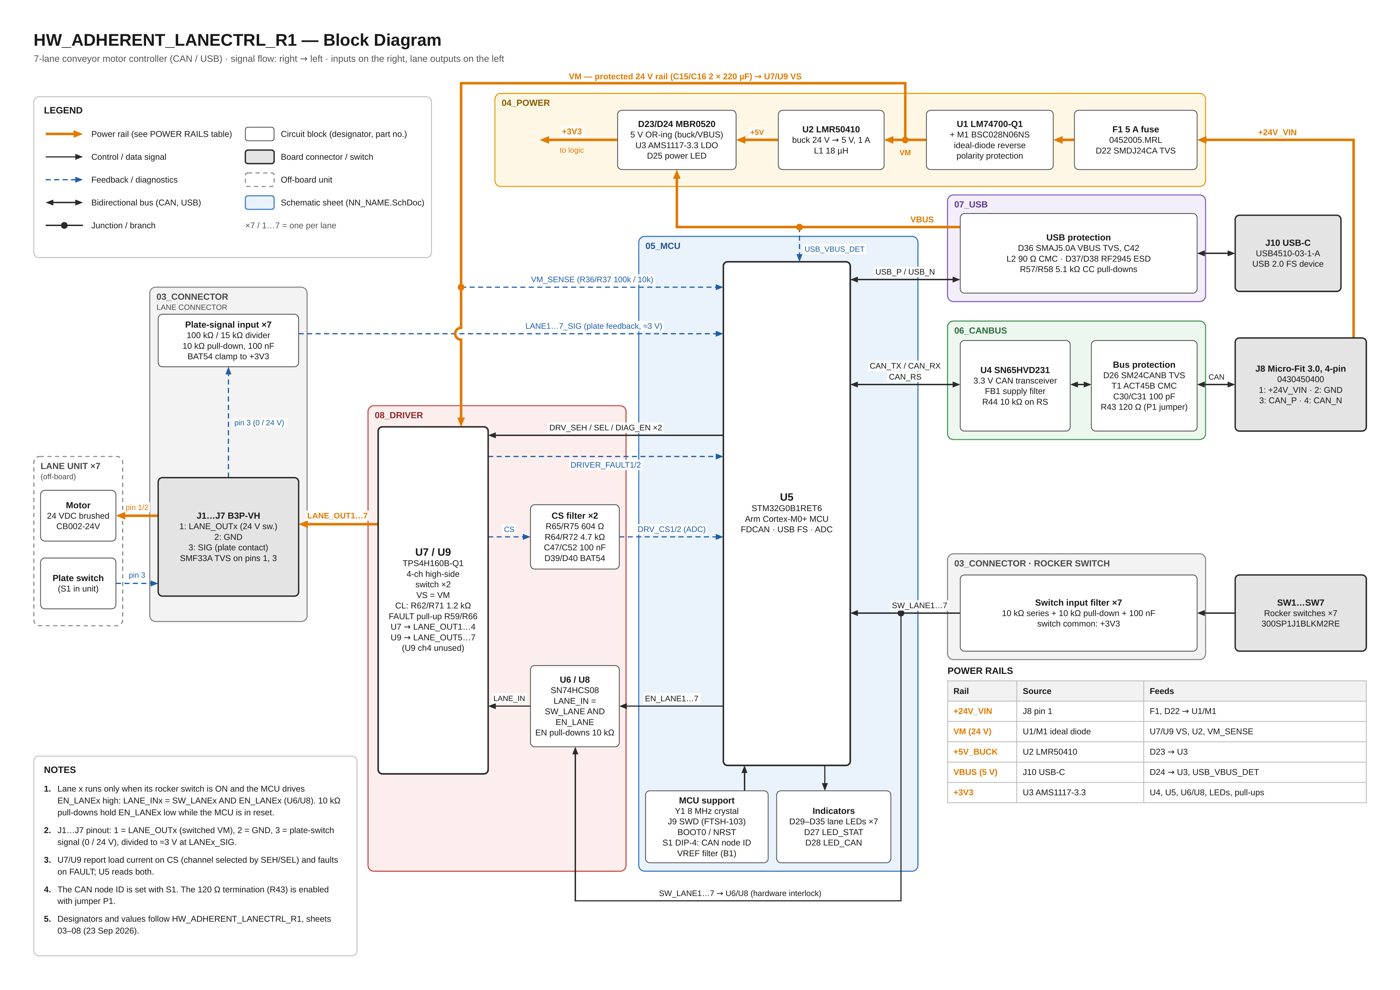
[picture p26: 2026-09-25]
HW/HW_ADHERENT_LANECTRL_R1/Docs/HW_ADHERENT_LANECTRL_R1_Block_Diagram_A3.png

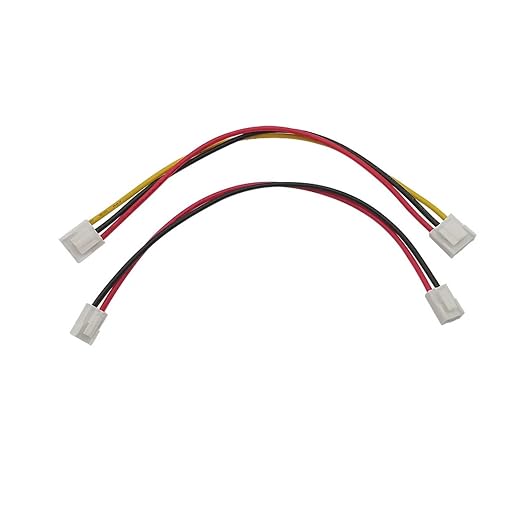
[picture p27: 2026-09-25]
HW/HW_ADHERENT_LANECTRL_R1/Docs/New_Docs/lanectrl_cable.jpg

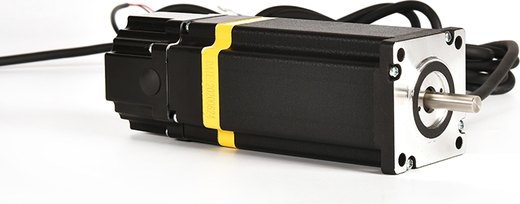
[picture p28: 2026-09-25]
.work/harness_img/EMTECH_MOTOR.jpg

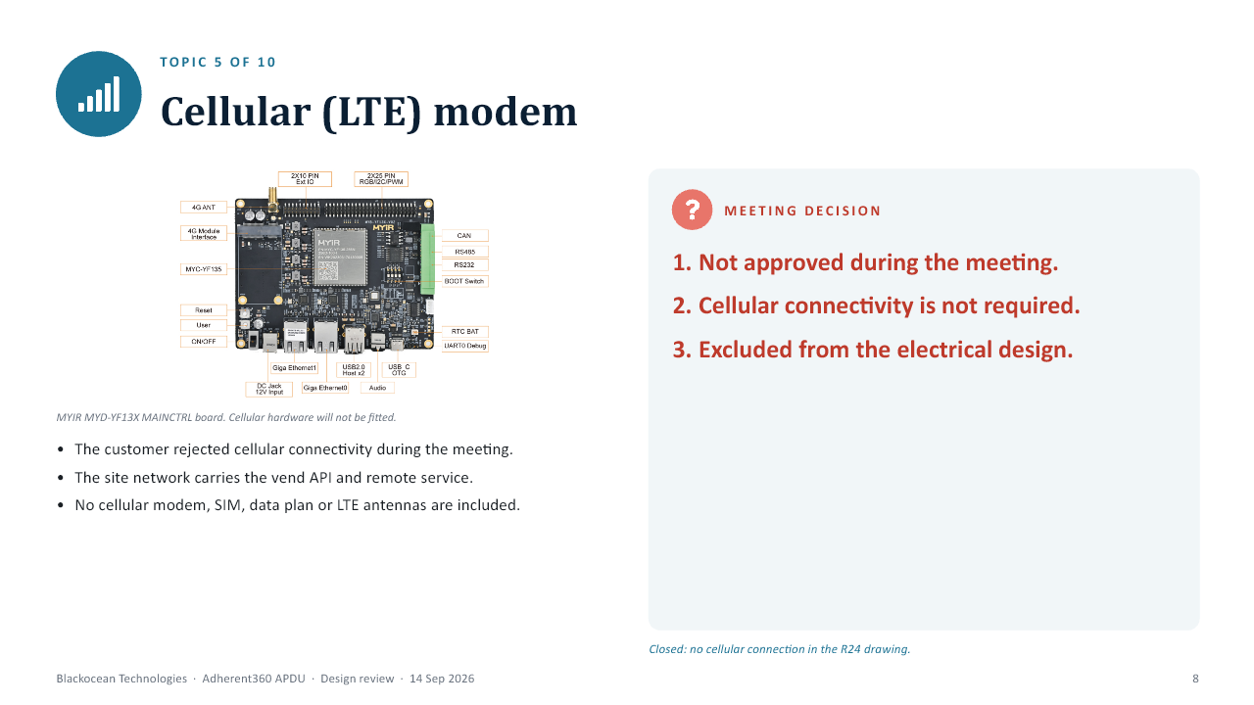
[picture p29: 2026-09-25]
.work/r24/after-8.png

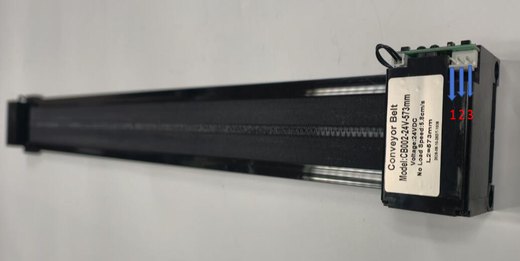
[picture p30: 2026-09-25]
.work/harness_img/CONVEYOR.jpg

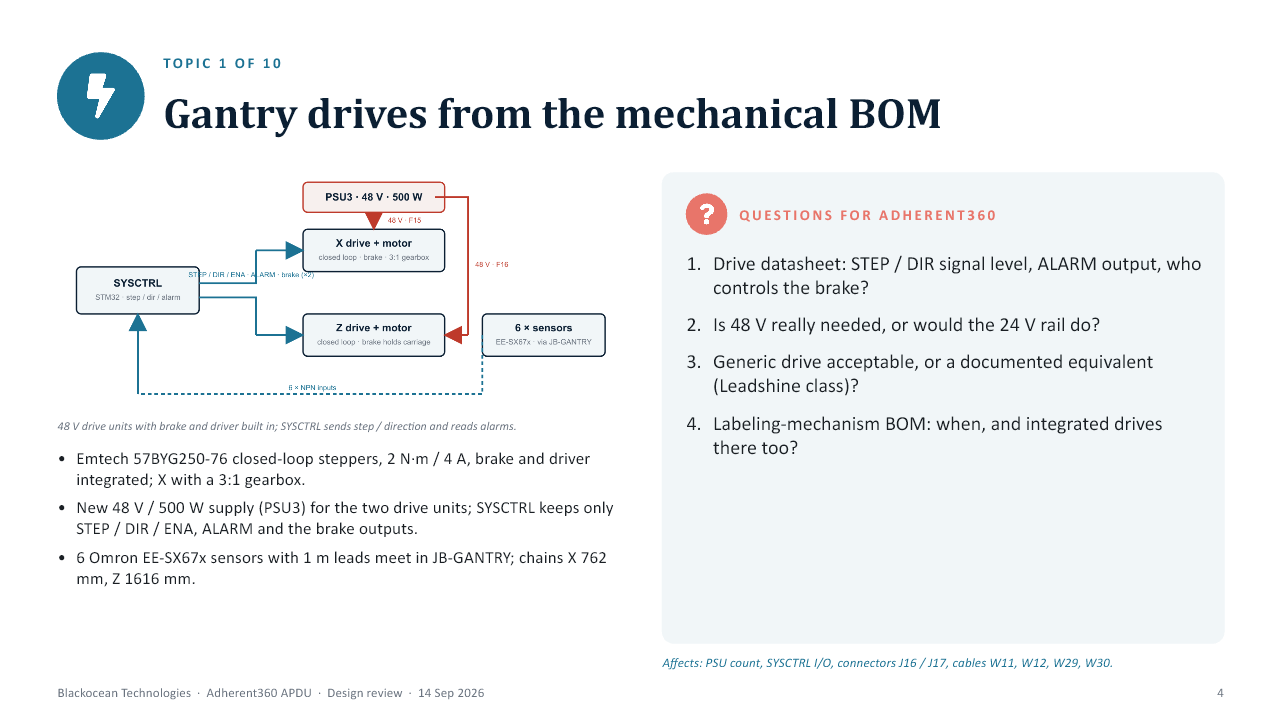
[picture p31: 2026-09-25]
.work/r24/after-4.png

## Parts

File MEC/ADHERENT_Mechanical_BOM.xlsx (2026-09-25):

 |  |  | ADHERENT MECHANICAL BILL OF MATERIALS
PROJECT NAME: |  | VENDING MACHINE
COMPANY: |  | FLORES ENGINEERING
ITEM | QTY | UOM | MATERIAL NAME / DESCRIPTION | MATERIAL SPECIFICATION | COMMODITY TYPE | PART NUMBER | MODULE/SYSTEM | ADDITIONAL SPECIFICATIONS/NOTES | LINK
1 | 2 |  | NEMA23 Closed Loop Stepper Motor with Brake and driver | 2N.m Holding Torque, 4A (Emtech) | SPECIAL PART | 57BYG250-76 | GANTRY AXIS | X and Z; brake and driver supplied. Integrated/separate driver packaging, 24 V compatibility and input current TBC. | https://www.alibaba.com/product-detail/Nema-23-Closed-Loop-Stepper-Motor_1601462210871.html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
2 | 1 |  | Planetary Gearbox for NEMA23 Stepper Motor | 3:1 Gear Ratio (Emtech Brand) | SPECIAL PART |  | GANTRY AXIS | For X-Axis only | https://www.alibaba.com/product-detail/EMTECH-Nema23-Planetary-Gearbox-3-10_1601689918939.html
3 | 1 | Pc | 24 V system power supply | 24 V / 21 A / 504 W; capacity validation pending | SPECIAL PART | Mean Well RSP-500-24 | CABINET / ALL RAILS | Replaces superseded 48 V supply. Gantry operation at 24 V pending exact drive datasheet. | https://www.meanwell.com/Upload/PDF/RSP-500/RSP-500-SPEC.PDF
4 | 3 |  | Slot Type Photosensor (Omron EE-SX674-WR or equivalent) | Slot Type Photosensor, NPN-Type, Pre-wired (1m) | SPECIAL PART | EE-SX674-WR | GANTRY AXIS | For Z-Axis overrun and homing sensors
5 | 3 |  | Slot Type Photosensor (Omron EE-SX672-WR or equivalent) | Slot Type Photosensor, NPN-Type, Pre-wired (1m) | SPECIAL PART | EE-SX672-WR | GANTRY AXIS | For X-Axis overrun and homing sensors
6 | 1 |  | Miuzei 20kg Servo Motor DS3218 |  | SPECIAL PART | Miuzei DS3218 | BASKET CARRIER | For Basket Tilting | https://www.amazon.com/dp/B07HNTKSZT?lv=shuf&amp&channelId=500&amp&plpRedirect=mhFallback
7 | 1 |  | Igus Micro Series Drag Chain | 762mm length, 1025.34P.A1 type mounting bracket | SPECIAL PART | E2i.17.025.028.0.1025.34P.A1 | GANTRY AXIS | For X-Axis Cable Management | https://www.igus.com/product/series-E2i-17?artnr=E2I.17.025.028.0
8 | 1 |  | Igus Micro Series Drag Chain | 1616mm length, 1015.34P.A2 type mounting bracket | SPECIAL PART | E2i.17.015.028.0.1015.34P.A2 | GANTRY AXIS | For Z-Axis Cable Management
9 | 2 | Sets | LINEAR RAIL (HGH15CA2R720ZAH) | 15mm Rail, 720mm LENGTH, 2 High Profile Blocks | SPECIAL PART | Hiwin HGH15CA2R710ZAH | GANTRY AXIS | With M6 Thread - Both Rail Ends
10 | 1 | Set | LINEAR RAIL (HGW15CC2R720Z0C) | 15mm Rail, 720mm LENGTH, 2 Wide Profile Blocks | SPECIAL PART | Hiwin HGW15CC2R710Z0C | GANTRY AXIS | With M6 Thread - Both Rail Ends
11 | 1 | Set | LINEAR RAIL (HGW15CC2R1550Z0C) | 15mm Rail, 1550mm LENGTH, 2 Wide Profile Blocks | SPECIAL PART | Hiwin HGW15CC2R1540Z0C | GANTRY AXIS | With M6 Thread - Both Rail Ends
12 | 2 | Pcs | Timing Idler Pulley (T5, 20 TEETH, 16mm) | Idler pulley, with Bearing on both sides, 8mm ID | SPECIAL PART | MISUMI P/N: E-AHTFW20-T5150-8 | GANTRY AXIS |  | https://sg.misumi-ec.com/vona2/detail/110311174409/
13 | 2 | Pcs | Timing Drive Pulley(T5, 20 TEETH, 16mm) | Drive Pulley, Plain bore type with threaded hole (set screw) | SPECIAL PART | MISUMI P/N: E-TTPA20T5150-B-P8 | GANTRY AXIS | Need to modify hub length to fit. | https://sg.misumi-ec.com/vona2/detail/110310928349?HissuCode=E-TTPA20T5150-B-P8
14 | 1 | Pc | Timing Belt (T5, 15mmWidth, 3300mm Length, 660 Teeth) | Polyurethane Material, with Steel Core | SPECIAL PART | MISUMI P/N: E-LTTBO-T5150-660 | GANTRY AXIS | Note: Actual required length is only 3275mm or 655 teeth | https://sg.misumi-ec.com/vona2/detail/110310703709?HissuCode=E-LTTBO-T5150-660
15 | 1 | Pc | Timing Belt (T5, 15mmWidth, 1650mm Length, 330 Teeth) | Polyurethane Material, with Steel Core | SPECIAL PART | MISUMI P/N: E-LTTBO-T5150-330 | GANTRY AXIS | Note: Actual required length is only 1630mm or 326 teeth | https://sg.misumi-ec.com/vona2/detail/110310703709?HissuCode=E-LTTBO-T5150-330
16 | 1 | Pc | Ethernet panel-mount RJ45 adapter | Shielded Cat5e; RJ45 female × female; black plastic | STANDARD PART | 1422N13 | CABINET / NETWORK | McMaster-Carr; J2 rear panel; 0.95 in (24.13 mm) cutout; 0.14 in mounting holes; fasteners included | https://www.mcmaster.com/product/1422N13
17 | 10 | Pcs | LANECTRL front metal bracket | Per user-supplied DWG; PCB fit not yet verified | CUSTOM PART | LANE DRAWING SPACE FOR UMIT.DWG | LANE ROWS | One per row assumed; confirm drawing quantity and button/LED clearances. | 01_CAD_MODELS/LANE DRAWING SPACE FOR UMIT.DWG
18 | 70 | Pcs | Conveyor assembly with DC motor | 24 V; <=0.2 A no-load; 5.8 cm/s; <=6 kg | SPECIAL PART | CB002-24V-573mm | LANE ROWS | Bench test at 24 V: 190 mA running, 280–310 mA braked, about 0.5 A stalled. Driven on/off by LANECTRL R1 high-side switches (no reversal). SIGNAL = 24 V dry contact; confirm pin reference on a real harness. | Conveyor belt(CB002-24V-573mm).pdf
19 | 1 | Set | Electrical controllers, wiring and protection | Authoritative quantities and selections in electrical workbook | REFERENCE | ../SYS/ADHERENT_Electrical_Tables.xlsx | SYSTEM | Reference only: use the single System parts sheet; do not duplicate purchase lines. | ../SYS/ADHERENT_Electrical_Tables.xlsx
20 | 1 | Set | Labeling mechanism parts | Chuck/jaw motors, servo, sensor and marker require selection confirmation | REFERENCE | See electrical BOM and OpenItems O10/O11 | LABELING | Reference only; unresolved MPNs and marker power prevent purchase release. | ../SYS/ADHERENT_Electrical_Tables.xlsx
21
22
23
24
25
26
27
28
29
30
31
32
33
34
35
36
37
38
39
40
41
42
43
44
45
46
47
48
49
50
51
52
53
54
55
56
57
58
59
60
61
62
63
64
65
66
67
68
69
70
71
72
73
74
75
76
77
78
79
80
81
82
83
84
85
86
87
88
89
90
91
92
93
94
95
96

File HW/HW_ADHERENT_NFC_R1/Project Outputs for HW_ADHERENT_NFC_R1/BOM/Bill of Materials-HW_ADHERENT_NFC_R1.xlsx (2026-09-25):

Line # | Name | Description | Designator | Quantity | Manufacturer 1 | Manufacturer Part Number 1 | Manufacturer Lifecycle 1 | Supplier 1 | Supplier Part Number 1 | Supplier Unit Price 1 | Supplier Subtotal 1
 | 47uF 80V | 47 µF 80 V Aluminum Electrolytic Capacitors Radial, Can - SMD 2000 Hrs @ 105°C | C1 | 1
 | CAP CER 0.22UF 50V X7R 0603 | 0.22 µF ±10% 50V Ceramic Capacitor X7R 0603 (1608 Metric) | C2 | 1
 | 100nF 25V | 0.1 µF ±10% 50V Ceramic Capacitor X7R 0603 (1608 Metric) | C3 | 1
 | 0.1uF 16V | 0.1 µF ±20% 16V Ceramic Capacitor X7R 0603 (1608 Metric) | C4 | 1
 | 1uF | CAP CER 1UF 50V X5R 0603 | C5 | 1
 | 0.1uF 100V | CAP CER 0.1UF 100V X7R 0603 | C6 | 1
 | 22uF 35V | 22 µF ±20% 35V Ceramic Capacitor X5R 1206 (3216 Metric) | C7 | 1
 | 1 µF | CAP0603 X7R 1UF 10% 25V | C8, C19 | 2 |  |  |  | DigiKey | 4713-GMC10X7R105K25NTCT-ND
 | 10 µF | CAP CER 10UF 50V X5R 0805 | C9 | 1 |  |  |  | DigiKey | 490-18663-1-ND
 | GCM188R71H104KA57J | CAP CER 0.1UF 50V X7R 0603 | C10, C12, C13, C14, C15, C16 | 6 |  |  |  | DigiKey | 490-8020-1-ND
 | 4.7 µF | CAP CER 4.7UF 50V X7R 0805 | C11 | 1 |  |  |  | DigiKey | 490-GRM21BZ71H475KE15KCT-ND
 | 8.2 pF | CAP0402 COG 8.2PF 5% 25V | C17, C18 | 2 |  |  |  | DigiKey | 4713-GMC04CG8R2J25NTCT-ND
 | 10000 pF | CAP CER 0603 10NF 16V X7R 10% | C20 | 1 |  |  |  | DigiKey | 399-C0603C103K4RECTUCT-ND
 | 47pF | 47 pF ±1% 200V Ceramic Capacitor C0G, NP0 0603 (1608 Metric) | C21, C24 | 2
 | 10uF | CAP CER 10UF 25V X5R 0603 | C22 | 1
 | 100nF | CAP CER 0.1UF 50V X7R 0603 | C23 | 1
 | 10uF | CAP CER 10UF 25V X5R 0603 | C25, C26 | 2
 | 1uF 16V | Multilayer Ceramic Capacitors MLCC - SMD/SMT 0603 1.0uF 16volts X5R 10% | C27, C33, C43 | 3
 | 10000pF | 10000 pF ±10% 16V Ceramic Capacitor X7R 0603 (1608 Metric) | C28, C32, C34, C36, C38, C42 | 6
 | 10pF 50V | 10 pF ±1% 50V Ceramic Capacitor C0G, NP0 0603 (1608 Metric) | C29, C30 | 2
 | 100uF 25V | 100 µF 25 V Aluminum - Polymer Capacitors Radial, Can - SMD 24mOhm 5000 Hrs @ 105°C | C31 | 1
 | 2.2uF | 2.2 µF ±10% 25V Ceramic Capacitor X5R 0603 (1608 Metric) | C35, C37, C39, C41 | 4
 | 0.1uF 16V | 0.1 µF ±10% 16V Ceramic Capacitor X7R 0603 (1608 Metric) | C40 | 1
 | 150pF 50V | 150 pF ±2% 50V Ceramic Capacitor C0G, NP0 0402 (1005 Metric) | C44, C55 | 2
 | 10pF 50V | CAP0402 COG 10PF 2% 50V | C45, C48, C50, C54 | 4
 | 33pF 50V | 33 pF ±1% 50V Ceramic Capacitor C0G, NP0 0402 (1005 Metric) | C46, C52 | 2
 | 180pF 50V | 180 pF ±1% 50V Ceramic Capacitor C0G, NP0 0402 (1005 Metric) | C47, C53 | 2
 | 360pF 50V | 360 pF ±5% 50V Ceramic Capacitor C0G, NP0 0402 (1005 Metric) | C49, C51 | 2
 | SMDJ33CA | 53.3V Clamp 56.3A Ipp Tvs Diode Surface Mount DO-214AB (SMCJ) | D1 | 1
 | LTST-C191KRKT | LED RED CLEAR SMD | D2 | 1
 | LED RED CLEAR SMD | Red 631nm LED Indication - Discrete 2V 0603 (1608 Metric) | D3, D4 | 2
 | 0452002.MRL | 2 A 125 V 125 V Fuse Board Mount (Cartridge Style Excluded) Surface Mount 2-SMD, Square End Block | F1 | 1
 | BLM21PG121SN1D | Ferrite Bead, 120 Ohm @ 100MHz, 500mA, 250 mOhm Max | FB1, FB2 | 2 |  |  |  | Digi-Key | 490-1005-1-ND
 | ACT45B-510-2P-TL003 | 51 ÂµH @ 100 kHz 2 Line Common Mode Choke Surface Mount 2.8 kOhms @ 10 MHz 200mA DCR 1Ohm | FL1 | 1
 | BLM18PG221SN1D | 220 Ohms @ 100 MHz 1 Power Line Ferrite Bead 0603 (1608 Metric) 1.4A 100mOhm | FL2 | 1
 | 0430450400 | Connector Header Through Hole, Right Angle 4 position 0.118" (3.00mm) | J1 | 1
 | SWR201-NRTN-S03-SA-WH | Connector | J2 | 1
 | CONN HEADER SMD 10POS 1.27MM | Connector Header Surface Mount 10 position 0.050" (1.27mm) | J3 | 1
 | 5055670271 | Connector Header Surface Mount, Right Angle 2 position 0.049" (1.25mm) | J4 | 1
 | 18uH | 18 µH Semi-Shielded Drum Core, Wirewound Inductor 2.2 A 81mOhm Nonstandard | L1 | 1
 | LQW18CNR47J0HD | Description | L2, L3 | 2
 | BSC028N06NS | MOSFET'ler N-Ch 60V 100A TDSON-8 OptiMOS 3 | M1 | 1
 | RC0603FR-07100KL | RES SMD 100K OHM 1% 1/10W 0603 | R1 | 1
 | RES 10K OHM 1% 1/8W 0603 | 10 kOhms ±1% 0.125W, 1/8W Chip Resistor 0603 (1608 Metric) Anti-Sulfur Thin Film | R2 | 1
 | 88.7k | 88.7 kOhms ±1% 0.125W, 1/8W Chip Resistor 0603 (1608 Metric) Automotive AEC-Q200 Thick Film | R3 | 1
 | 22.1k | 22.1 kOhms ±1% 0.1W, 1/10W Chip Resistor 0603 (1608 Metric) Moisture Resistant Thick Film | R4 | 1
 | 330 Ohms | RES SMD 330 OHM 1% 1/5W 0603 | R5 | 1 |  |  |  | DigiKey | A129541CT-ND
 | 10 kOhms | RES 10K OHM 1% 1/16W 0402 | R6, R7, R8, R9 | 4 |  |  |  | DigiKey | RMCF0402FT10K0CT-ND
 | 0 Ohms | RES 0 OHM JUMPER 1/16W 0402 | R10 | 1 |  |  |  | DigiKey | RMCF0402ZT0R00CT-ND
 | 1 kOhms | RES 1K OHM 1% 1/16W 0402 | R11, R12 | 2 |  |  |  | DigiKey | RMCF0402FT1K00CT-ND
 | 56 Ohms | 56 Ohms ±1% 0.063W, 1/16W Chip Resistor 0402 (1005 Metric) Automotive AEC-Q200 Thick Film | R13, R14 | 2
 | 330 Ohms | 330 Ohms ±1% 0.063W, 1/16W Chip Resistor 0402 (1005 Metric) Automotive AEC-Q200 Thick Film | R15 | 1
 | 10 kOhms | RES 10K OHM 0.1% 1/16W 0603 | R16, R17 | 2 |  |  |  | DigiKey | RNCS0603BKE10K0CT-ND
 | 560mOhms | 560 mOhms ±1% 0.125W, 1/8W Chip Resistor 0402 (1005 Metric) Current Sense Thick Film | R18, R19 | 2
 | SMD |  | T1, T2, T3, T4, T5, T6 | 6
 | LM74700QDBVRQ1 | OR Controller N+1 ORing Controller N-Channel 1:1 SOT-23-6 | U1 | 1
 | LMR50410XDBVR | Buck Switching Regulator IC Positive Adjustable 1V 1 Output 1A SOT-23-6 | U2 | 1
 | AP2112K-3.3TRG1 | Linear Voltage Regulator IC Positive Fixed 1 Output 600mA SOT-25 | U3 | 1
 | STM32F103C8T6 | ARM Cortex-M3 32-bit MCU, 64 KB Flash, 20 KB Internal RAM, 37 I/Os, 48-pin LQFP, -40 to 85 degC, Tray | U4 | 1
 | SN65HVD232DR | 1Mbps Transceiver 3V~3.6V SOIC-8 CAN ICs ROHS | U5 | 1
 | CPC1014NTR | SSR RELAY SPST-NO 400MA 0-60V | U6 | 1
 | ST25R200-BMET | Powerful general-purpose NFC reader for consumer and industrial applications | U7 | 1
 | CS11337-27.12M | 27.12 MHz ±30ppm Crystal 6pF 60 Ohms 4-SMD, No Lead | U8 | 1
 | ECS-80-8-30Q-VS-TR | 8 MHz Â±30ppm Crystal 8pF 100 Ohms 2-SMD, No Lead | Y1 | 1

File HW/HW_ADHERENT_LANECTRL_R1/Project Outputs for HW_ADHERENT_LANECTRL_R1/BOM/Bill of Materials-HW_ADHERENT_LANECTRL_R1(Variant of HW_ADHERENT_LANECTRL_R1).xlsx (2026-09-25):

Comment | Description | Designator | Footprint | LibRef | Quantity | Part Number | Manufacturer Part Number | Manufacturer Part Name | MPN
BEAD FERRITE 120R 1LN SMD 0603 | BEAD FERRITE 120R 1LN SMD 0603 | B1 | F0603 | BEAD FERRITE 120R 1LN SMD 0603 | 1 |  |  | BLM18PG121SN1D
100nF | 0.1 µF ±10% 50V Ceramic Capacitor X7R 0603 (1608 Metric), CAP CER 0.1UF 50V X7R 0603 | C1, C2, C3, C4, C5, C6, C7, C8, C9, C10, C11, C12, C13, C14, C29, C44, C45, C50, C51 | CAP0603 | CAP0603_100nF_50V, CAP0603_100nF_1 | 19 |  | C0603C104K5RAC7867, [NoParam]
220uF 50V | 220 µF 50 V Aluminum Electrolytic Capacitors Radial, Can - SMD 180mOhm @ 100kHz 2000 Hrs @ 105°C | C15, C16 | CAP_EEEFT1H221AV | EEEFT1H221AV | 2 |  | EEE-FT1H221AV
CAP CER 0.22UF 50V X7R 0603 | 0.22 µF ±10% 50V Ceramic Capacitor X7R 0603 (1608 Metric) | C17 | SMC0603 | CAP0603_0.22UF_50V | 1 |  | GCM188R71H224KA64D
CAP CER 10UF 50V X5R 1206 | 10 µF ±10% 50V Ceramic Capacitor X5R 1206 (3216 Metric) | C18 | SMC1206 | CAP1206_10UF_50V | 1 |  | CL31A106KBHNNNE
CAP CER 0.1UF 50V X7R 0603 | 0.1 µF ±10% 50V Ceramic Capacitor X7R 0603 (1608 Metric) | C19 | SMC0603 | CAP0603_0.1UF_50V_2 | 1 |  | CL10B104KB8NNNL
100nF 25V | 0.1 µF ±10% 50V Ceramic Capacitor X7R 0603 (1608 Metric) | C20, C27, C39, C47, C52 | CAP0603 | CAP0603_100nF | 5 |  | CL10B104KA8NNNC
0.1uF 16V | 0.1 µF ±20% 16V Ceramic Capacitor X7R 0603 (1608 Metric) | C21 | CAP0603 | C0603C104M4RACTU | 1
1uF | CAP CER 1UF 50V X5R 0603 | C22 | CAP0603 | MSASU168SB5105MTNA01 | 1
0.1uF 100V | CAP CER 0.1UF 100V X7R 0603 | C23 | CAP0603 | GRM188R72A104KA35D | 1
22uF 35V | 22 µF ±20% 35V Ceramic Capacitor X5R 1206 (3216 Metric) | C24 | CAP1206 | CAP1206_22uF_35V | 1 |  | C3216X5R1V226M160AC
10uF | 10 µF ±10% 25V Ceramic Capacitor X5R 0603 (1608 Metric) | C25, C26 | CAP0603 | CAP0603_10uF_25V | 2 |  | GRM188R61E106KA73J
CAP CER 10UF 10V X5R 0603 | 10 µF ±10% 10V Ceramic Capacitor X5R 0603 (1608 Metric) | C28 | SMC0603 | CAP0603_10UF_10V | 1 |  | CL10A106KP8NNNC
CAP CER 100PF 50V C0G/NP0 0603 | 100 pF ±5% 50V Ceramic Capacitor C0G, NP0 0603 (1608 Metric) | C30, C31 | CAP0603 | CAP0603_100PF | 2 |  | CL10C101JB8NNNC
4.7uF | 4.7 µF ±20% 10V Ceramic Capacitor X5R 0603 (1608 Metric) | C32 | CAP0603 | CAP0603_4.7uF_10V | 1 |  | GRM185R61A475ME11D
CAP CER 1UF 16V X7R 0603 | 1 µF ±10% 16V Ceramic Capacitor X7R 0603 (1608 Metric) | C33, C34, C35, C36, C40, C41 | SMC0603 | CAP0603_1UF_16V | 6 |  | CGA3E1X7R1C105K080AC
8.2pF 25V | CAP0402 COG 8.2PF 5% 25V | C37, C38 | 0402_C | GMC04CG8R2J25NT | 2
CAP CER 0.1UF 50V X7R 0402 | 0.1 µF ±10% 50V Ceramic Capacitor X7R 0402 (1005 Metric) | C42 | SMC0402 | CAP0402_0.1UF_50V_1 | 1 |  | GCM155R71H104KE02J
EEH-ZA1H220P | 22 µF 50 V Aluminum - Polymer Capacitors Radial, Can - SMD 80mOhm 10000 Hrs @ 105°C | C43, C49 | CAP_EEHZA1H220P | EEH-ZA1H220P | 2 |  |  |  | EEH-ZA1H220P
0.1uF 10V | 0.1 µF ±10% 10V Ceramic Capacitor X7R 0603 (1608 Metric) | C46, C48 | CAP0603 | CAP0603_0.1uF_10V | 2 |  | 0603ZC104KAT2A
BAT54WS-7-F | Diode 30 V 100mA Surface Mount SOD-323 | D1, D3, D7, D8, D13, D14, D19, D39, D40 | SOD2513X120N | BAT54WS-7-F | 9 |  |  |  | BAT54WS-7-F
SMF33A | 53.3V Clamp 3.8A Ipp Tvs Diode Surface Mount SOD-123F | D2, D4, D5, D6, D9, D11, D12, D15, D16, D17, D18, D20, D21 | SOD-123F - duplicate | SMF33A | 13 |  |  |  | SMF33A
SMDJ24CA | 38.9V Clamp 77.1A Ipp Tvs Diode Surface Mount DO-214AB (SMCJ) | D22 | DIONM9059X262N | SMDJ24CA | 1 |  |  |  | SMDJ24CA
MBR0520LT1G | Diode 20 V 500mA Surface Mount SOD-123 | D23, D24 | SOD3716X135N | MBR0520LT1G | 2
LTST-C191KRKT | LED RED CLEAR SMD | D25 | LED0603 | LED_1 | 1 |  | LTST-C191KRKT
CAN | TVS DIODE 24VWM 50VC SOT23-3 | D26 | SOT23_3-DIODE | SM24CANB-02HTG_TVS | 1 |  | SM24CANB-02HTG
LED GREEN | Green 570nm LED Indication - Discrete 2.1V 0805 (2012 Metric) | D27 | LED0805 | LED0805_GREEN | 1 |  | QTLP630C4TR
LED YELLOW CLEAR SMD | Yellow 591nm LED Indication - Discrete 2.1V 0603 (1608 Metric) | D28 | Lite-On_Yellow_0603 | LTST-C191KSKT | 1 |  | LTST-C191KSKT
SMAJ5.0A | 9.2V Clamp 43.5A Ipp Tvs Diode Surface Mount DO-214AC (SMA) | D36 | SMAJ5.0A | SMAJ5.0A | 1 |  |  |  | SMAJ5.0A
TVS DIODE 7VWM 10VC 0402 | 10V (Typ) Clamp 2A (8/20µs) Ipp Tvs Diode Surface Mount 0402 | D37, D38 | Littelfuse_SESD0402_MFG | RF2945-000 | 2 |  | SESD0402X1BN-0010-098
0452005.MRL | FUSE BRD MNT 5A 125VAC/VDC 2SMD | F1 | FUSC6127X294N | 0452005.MRL | 1
BLM21PG121SN1D | 120 Ohms @ 100 MHz 1 Power Line Ferrite Bead 0805 (2012 Metric) 3A 30mOhm | FB1 | BEADC2012X105N/ | BLM21PG121SN1D | 1 |  |  |  | BLM21PG121SN1D
436500300 | Micro-Fit 3.0 Right-Angle Header, 3.00mm Pitch, Single Row, 3 Circuits, with Snap-in Plastic Peg PCB Lock, Tin, Glow-Wire Capable, Black | J1, J2, J3, J4, J5, J6, J7 | CONN_SD-43650-001_03_MOL/ | 436500300 | 7 |  | 436500300
0430450400 | Connector Header Through Hole, Right Angle 4 position 0.118" (3.00mm) | J8 | CONN_SD-43045-001_04_MOL | 0430450400 | 1 |  | 0430450400
FTSH-103-01-F-DV-TR | Connector Header Surface Mount 6 position 0.050" (1.27mm) | J9 | SAMTEC_FTSH-103-01-F-DV-TR | FTSH-103-01-F-DV-TR | 1
USB C REC 16P 3U" MID MNT 1.6MM | USB-C (USB TYPE-C) USB 2.0 Receptacle Connector 24 (16+8 Dummy) Position Board Edge, Cutout; Surface Mount; Through Hole, Right Angle | J10 | GCT_USB4510-03-1-A_REVA | USB4510-03-1-A_REVA | 1 |  | USB4510-03-1-A
18uH | 18 µH Semi-Shielded Drum Core, Wirewound Inductor 2.2 A 81mOhm Nonstandard | L1 | WE-LQS_6045 | 74404064180 | 1
CMC 100MA 2LN 90 OHM SMD | 2 Line Common Mode Choke Surface Mount 90 Ohms @ 100 MHz 100mA DCR 1.75Ohm | L2 | IND_MCZ1210AH_TDK | MCZ1210AH900L2T | 1 |  | MCZ1210AH900L2TA0G
BSC028N06NS | MOSFET'ler N-Ch 60V 100A TDSON-8 OptiMOS 3 | M1 | BSC028N06NS | BSC028N06NS | 1
Mounting Hole, 3 MM | Mounting Hole, 3 MM | MTG1, MTG2, MTG3, MTG4, MTG5, MTG6, MTG7, MTG8 | M3 Mounting Hole | MTG3MM_8 | 8
0022032021 | CONN HEADER VERT 2POS 2.54MM | P1 | THD 1x2p. male straight | Header 2 | 1 |  | 0022032021
10k %1 | Thick Film Resistors - SMD 0603 100 mW (1/10 W) 1% 10K | R1, R2, R3, R4, R11, R12, R13, R14, R21, R22, R23, R24, R27, R32 | RESIS_0603 | 0603WAF1002T5E | 14
100k %1 | -55℃~+155℃ 100kΩ 100mW 75V Thick Film Resistor ±1% ±100ppm/℃ 0603 Chip Resistor - Surface Mount ROHS | R5, R6, R15, R16, R25, R26, R33 | RESIS_0603 | 0603WAF1003T5E | 7
15k | -55℃~+155℃ 100mW 15kΩ 75V Thick Film Resistor ±1% ±100ppm/℃ 0603 Chip Resistor - Surface Mount ROHS | R7, R9, R17, R20, R28, R30, R34 | RESIS_0603 | 0603WAF1502T5E | 7
10k | -55℃~+155℃ 10kΩ 125mW 150V Thick Film Resistor ±1% ±100ppm/℃ 0805 Chip Resistor - Surface Mount ROHS | R8, R10, R18, R19, R29, R31, R35 | RES0805 | 0805W8F1002T5E | 7
RC0603FR-07100KL | RES SMD 100K OHM 1% 1/10W 0603 | R36 | FP-RC0603-0_55-MFG | CMP-2100-03662-2 | 1
RES 10K OHM 1% 1/8W 0603 | 10 kOhms ±1% 0.125W, 1/8W Chip Resistor 0603 (1608 Metric) Anti-Sulfur Thin Film | R37, R44, R59, R66, R67, R70, R73, R76, R77, R78, R79 | RES0603 | RES0603_10K_%1_1 | 11 |  | RNCP0603FTD10K0
88.7k | 88.7 kOhms ±1% 0.125W, 1/8W Chip Resistor 0603 (1608 Metric) Automotive AEC-Q200 Thick Film | R38 | RES0603 | CRCW060388K7FKEA | 1
22.1k | 22.1 kOhms ±1% 0.1W, 1/10W Chip Resistor 0603 (1608 Metric) Moisture Resistant Thick Film | R39 | RES0603 | RC0603FR-0722K1L | 1
RES 22K OHM 1% 1/10W 0603 | 10 kOhms ±1% 0.1W, 1/10W Chip Resistor 0603 (1608 Metric) Moisture Resistant Thick Film | R40 | SMR0603 | RES0603_22K_%1 | 1 |  | RC0603FR-0722KL
RES 33K OHM 1% 1/10W 0603 | 33 kOhms ±1% 0.1W, 1/10W Chip Resistor 0603 (1608 Metric) Moisture Resistant Thick Film | R41 | SMR0603 | RES0603_33K_%1 | 1 |  | RC0603FR-0733KL
330 Ohms | RES SMD 330 OHM 1% 1/5W 0603 | R42 | RES 0603_1608 | CRGH0603F330R | 1 | CRGH0603F330R
120 Ohms | RES SMD 120 OHM 1% 1/4W 1206 | R43 | RES 1206_3216 | AC1206FR-07120RL | 1 | AC1206FR-07120RL
RES 10K OHM 1% 1/10W 0603 | 10 kOhms ±1% 0.1W, 1/10W Chip Resistor 0603 (1608 Metric) Moisture Resistant Thick Film | R46, R47 | SMR0603 | RES0603_10K_%1 | 2 |  | RC0603FR-0710KL
1K | RES SMD 1K OHM 1% 1/10W 0603 | R48, R49 | R 0603(1608) | Res3_9 | 2 |  | RC0603FR-071KL
RES 100 OHM 1% 1/10W 0603 | 100 Ohms ±1% 0.1W, 1/10W Chip Resistor 0603 (1608 Metric) Moisture Resistant Thick Film | R50, R51, R52, R53, R54, R55, R56 | SMR0603 | RES0603_100R_%1_1 | 7 |  | RC0603FR-07100RL
RES SMD 5.1K OHM 1% 1/16W 0402 | 5.1 kOhms ±1% 0.063W, 1/16W Chip Resistor 0402 (1005 Metric) Automotive AEC-Q200 Thick Film | R57, R58 | SMR0402 | RES0402_5.1K_%1 | 2 |  | CRCW04025K10FKED
4K7 | RES SMD 4.7K OHM 1% 1/10W 0603 | R60, R61, R63, R64, R68, R69, R72, R74 | R 0603(1608) | Res3_9_1 | 8 |  | RC0603FR-074K7L
1.2kΩ | -55℃~+155℃ 1.2kΩ 100mW 75V Thick Film Resistor ±1% ±100ppm/℃ 0603 Chip Resistor - Surface Mount ROHS | R62, R71 | RES0603 | 0603WAF1201T5E | 2
604Ω | -55℃~+155℃ 100mW 604Ω 75V Thick Film Resistor ±1% ±100ppm/℃ 0603 Chip Resistor - Surface Mount ROHS | R65, R75 | RES0603 | 0603WAF6040T5E | 2
418121270804 | Dip Switch, 0.025A, 24Vdc, 4 Pos, Smd Rohs Compliant: Yes |Wurth Elektronik 418121270804 | S1 | 418121270804 | 418121270804 | 1 |  | 418121270804
300SP1J1BLKM2RE | Rocker Switch SPDT 0.4VA (AC/DC) 20 V Through Hole | SW1, SW2, SW3, SW4, SW5, SW6, SW7 | sw_300SP1J1BLKM2RE_ | 300SP1J1BLKM2RE | 7 |  |  |  | 300SP1J1BLKM2RE
ACT45B-510-2P | Ind Common Mode Filter Wirewound 51uH 2KOhm -30% to 50% 100KHz 200mA 1812 T/R | T1 | TDK_ACT45B-510-2P-TL003_0 | ACT45B-510-2P | 1 |  | ACT45B-510-2P-TL003
LM74700QDBVRQ1 | OR Controller N+1 ORing Controller N-Channel 1:1 SOT-23-6 | U1 | SOT95P280X145-6N/LM74700QDBVRQ1 | LM74700QDBVRQ1 | 1
LMR50410XDBVR | Buck Switching Regulator IC Positive Adjustable 1V 1 Output 1A SOT-23-6 | U2 | SOT95P280X145-6N/ | LMR50410XDBVR | 1 |  |  |  | LMR50410XDBVR
AMS1117-3.3 | Linear Voltage Regulator IC Positive Fixed 1 Output 1A SOT-223-3L | U3 | SOT-223-4_L6.5-W3.5-P2.30-LS7.0-BR | AMS1117-3.3 | 1
SN65HVD231QDR | 3.3-V CAN Transceiver with Sleep Mode | U4 | SOIC127P599X175-8N/ | SN65HVD231QDR | 1 |  |  |  | SN65HVD231QDR
STM32G0B1RET6 | ARM® Cortex®-M0+ STM32G0 Microcontroller IC 32-Bit 64MHz 512KB (512K x 8) FLASH 64-LQFP (10x10) | U5 | QFP50P1200X1200X160-64N | STM32G0B1RET6 | 1 |  |  |  | STM32G0B1RET6
SN74HCS08DR | AND Gate IC 4 Channel Schmitt Trigger Input 14-SOIC | U6, U8 | SOIC127P600X175-14N | SN74HCS08DR | 2 |  |  |  | SN74HCS08DR
TPS4H160BQPWPRQ1 | 40-V, 160-mΩ, 4-ch automotive smart high-side switch with adjustable current limit | U7, U9 | SOP65P640X120-29N | TPS4H160BQPWPRQ1 | 2 |  |  |  | TPS4H160-Q1
ECS-80-8-30Q-VS-TR | CRYSTAL 8.0000MHZ 8PF SMD | Y1 | XTAL_ECS-80-8-30Q-VS-TR | ECS-80-8-30Q-VS-TR | 1

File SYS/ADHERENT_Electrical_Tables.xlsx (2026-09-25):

Adherent system parts
References match the diagram. Dimensions in mm. TBC = not confirmed; provisional models are for placement only.
Open matching system diagram (https://github.com/Microver-Electronics/Adherent/blob/main/SYS/ADHERENT_System_Wiring_Diagram.png)
Diagram ref. | Component | Part number / model | Qty | Location in system | Product / source link | STEP / drawing link | Rough dimensions (mm)
J2 | RJ45 panel adapter | McMaster 1422N13 | 1 | Rear panel | McMaster product (https://www.mcmaster.com/product/1422N13) | TBC | Cutout Ø24.13; envelope TBC
J1 | AC inlet / filter / breaker | FN9264-6-06 candidate; breaker TBC | 1 | AC input | TBC | TBC | TBC
PSU1 | 24 V power supply | Mean Well RSP-500-24 | 1 | Power cabinet | Mean Well (https://www.meanwell.com/Upload/PDF/RSP-500/RSP-500-SPEC.PDF) | Dimension drawing (https://www.meanwell.com/Upload/PDF/RSP-500/RSP-500-SPEC.PDF#page=4) | 230 × 127 × 40.5
MAINCTRL | Supervisory controller | MYIR MYD-YF13X; exact SKU TBC | 1 | Control cabinet | MYIR product (https://www.myirtech.com/list.asp?id=727) | Provisional STEP (https://github.com/Microver-Electronics/Adherent/blob/main/MEC/Board_STEP_Models/MAINCTRL_MYIR_MYD-YF13X/MAINCTRL_MYD-YF13X_Provisional_Placement_R1.step) | PCB 137.29 × 105; model 137.7 × 113.1 × 20.1 (estimated)
SYSCTRL | Machine controller | HW_ADHERENT_SYSCTRL_R1 | 1 | Control cabinet | Custom board (https://github.com/Microver-Electronics/Adherent/blob/main/HW/HW_ADHERENT_SYSCTRL_R1) | TBC | TBC; PCB layout pending
BUCK12 | Onboard 24 V → 12 V SMPS | TBC | 1 | Inside SYSCTRL | TBC | Within SYSCTRL | No separate mounting envelope
SYSCTRL-PWR | Power connectors | MPNs TBC | 1 | Inside SYSCTRL | TBC | Within SYSCTRL | No separate distribution box
IOCTRL-01, IOCTRL-02 | Door I/O controllers (8DI / 8RO each) | Waveshare ESP32-S3-ETH-8DI-8RO | 2 | Control cabinet; I/O split between modules TBC | Waveshare product (https://www.waveshare.com/wiki/ESP32-S3-ETH-8DI-8RO) | Provisional STEP (https://github.com/Microver-Electronics/Adherent/blob/main/MEC/Board_STEP_Models/IOCTRL_Waveshare_ESP32-S3-ETH-8DI-8RO/IOCTRL_Provisional_Placement_R1.step) | 175 × 90 × 40 provisional, per module; reserve space for 2; PoE-reference fit unverified
LANECTRL-01…10 | Row controllers | HW_ADHERENT_LANECTRL_R1 (STM32G0B1, 2 × TPS4H160 high-side) | 10 | Front of rows 01–10 | Custom board (https://github.com/Microver-Electronics/Adherent/blob/main/HW/HW_ADHERENT_LANECTRL_R1) | Board STEP (https://github.com/Microver-Electronics/Adherent/blob/main/MEC/HW_ADHERENT_LANECTRL_R1/HW_ADHERENT_LANECTRL_R1%28Variant%20of%20HW_ADHERENT_LANECTRL_R1%29.step) | PCB 504 × 60 × 1.6, 4 layers; 8 × M3; bracket fit unverified
CONVEYOR-01…10 | Conveyors (7 per row) | CB002-24V-573mm | 70 | Rows 01–10 | Supplier sheet (https://github.com/Microver-Electronics/Adherent/blob/main/MEC/Conveyor%20belt(CB002-24V-573mm).pdf) | Supplier drawing (https://github.com/Microver-Electronics/Adherent/blob/main/MEC/Conveyor%20belt(CB002-24V-573mm).pdf) | L 676.33; belt L2 573; W/H TBC
X | X stepper + brake + driver | Emtech 57BYG250-76 | 1 | Gantry X axis | Emtech listing (https://www.alibaba.com/product-detail/Nema-23-Closed-Loop-Stepper-Motor_1601462210871.html) | TBC | TBC; motor/driver package pending
X-GB | X planetary gearbox (3:1) | Emtech exact model TBC | 1 | X motor assembly | Emtech listing (https://www.alibaba.com/product-detail/EMTECH-Nema23-Planetary-Gearbox-3-10_1601689918939.html) | TBC | TBC
Z | Z stepper + brake + driver | Emtech 57BYG250-76 | 1 | Gantry Z axis | Emtech listing (https://www.alibaba.com/product-detail/Nema-23-Closed-Loop-Stepper-Motor_1601462210871.html) | TBC | TBC; motor/driver package pending
SERVO | Basket tilt servo | Miuzei DS3218; variant TBC | 1 | Basket carrier | BOM supplier (https://www.amazon.com/dp/B07HNTKSZT) | TBC | TBC; exact variant pending
X-SENS | X position sensors | Omron EE-SX672-WR; suffix TBC | 3 | Gantry X → SYSCTRL | Omron product (https://www.ia.omron.com/products/family/436/) | Omron drawings (https://www.ia.omron.com/products/family/436/dimension.html) | Envelope TBC; supplied lead 1000
Z-SENS | Z position sensors | Omron EE-SX674-WR; suffix TBC | 3 | Gantry Z → SYSCTRL | Omron product (https://www.ia.omron.com/products/family/436/) | Omron drawings (https://www.ia.omron.com/products/family/436/dimension.html) | Envelope TBC; supplied lead 1000
CHUCK | Chuck rotate stepper + gearbox | Catalog reference 6627T113 | 1 | Labeling mechanism | Catalog reference (https://www.mcmaster.com/6627T113/) | TBC | TBC; exact MPN not verified
JAWS | Chuck jaw stepper | Catalog reference 6627T357 | 1 | Labeling mechanism | Catalog reference (https://www.mcmaster.com/6627T357/) | TBC | TBC; exact MPN not verified
JAW-SENS | Jaw home sensor | TBC | 1 | Jaw assembly → SYSCTRL | TBC | TBC | TBC
MARKER | Label marker / printer | TBC | 1 | Labeling mechanism | TBC | TBC | TBC
K1–K4 | 12 V latches | TBC | 4 | Main / retrieval / return / table | TBC | TBC | TBC
DI1–DI5 | Door position sensors | TBC | 5 | 4 latch doors + front access | TBC | TBC | TBC
STACK | 12 V status light | TBC | 1 | Machine status indicator | TBC | TBC | TBC
ANT-NFC | NFC antenna | Molex 1462362151 | 1 | Reader location TBC | DigiKey product (https://www.digikey.com/en/products/detail/molex/1462362151/15204370) | Molex drawing (https://www.molex.com/content/dam/molex/molex-dot-com/products/automated/en-us/salesdrawingpdf/146/146236/1462362131_sd.pdf) | 15 × 15 × 0.27; cable 102
NFC | NFC reader board (custom PCB) | HW_ADHERENT_NFC_R1 (STM32F103C8 + ST25R200); R1 in design | 1 | Position TBC; 24 V + CAN 4-pin Micro-Fit, bus position / feed TBC | Custom board | Board STEP (R1 draft) | TBC; PCB layout in progress
BRACKET | LANECTRL front metal bracket | LANECTRL bracket drawing | 10 | Front of rows 01–10 | Project reference (https://github.com/Microver-Electronics/Adherent/blob/main/MEC/01_CAD_MODELS/Draw%C4%B1ng/LANECTRL_BRACKET_REFERENCE.md) | Bracket DWG (https://github.com/Microver-Electronics/Adherent/blob/main/MEC/01_CAD_MODELS/Draw%C4%B1ng/LANE%20DRAWING%20SPACE%20FOR%20UMIT.DWG) | Per DWG; PCB fit TBC
WIFI | Wi-Fi / BT antenna | Not selected | 0 | Network block (optional) | Not selected | Not selected | Not selected
CAM | Camera / OCR | Not selected | 0 | Labeling block (excluded) | Not selected | Not selected | Not selected
DOORACT | Door actuators | Not selected | 0 | Door block (excluded) | Not selected | Not selected | Not selected
LAN | Pharmacy LAN / router | Site equipment | 0 | External site network | Site supplied | N/A | Outside machine
IPAD | iPad | Site equipment | 0 | External user device | Site supplied | N/A | Outside machine
CLOUD | Adherent servers | Hosted service | 0 | External server | N/A | N/A | No machine hardware

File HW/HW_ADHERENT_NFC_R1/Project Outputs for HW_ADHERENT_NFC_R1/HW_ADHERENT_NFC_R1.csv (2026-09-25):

manufacturer | Comment | Description | Designator | Footprint | LibRef | Quantity | JLCPCB PART# | ManIfacturer | Manifacturer | Manifacturer | Manufacturer 1 | Manufacturer 2 | Manufacturer Part Number 2 | Manufacturer Part Number 1 | Manufacturer Part Number | MPN | MP | LCSC Manufacturer Part Number | LCSC Part Number
Panasonic Industry | 47uF 80V | 47 µF 80 V Aluminum Electrolytic Capacitors Radial, Can - SMD 2000 Hrs @ 105°C | C1 | CAP_EEEFK1K470P | EEE-FK1K470P | 1
 | CAP CER 0.22UF 50V X7R 0603 | 0.22 µF ±10% 50V Ceramic Capacitor X7R 0603 (1608 Metric) | C2 | SMC0603 | CAP0603_0.22UF_50V | 1 |  |  |  |  |  |  |  |  | GCM188R71H224KA64D
 | 100nF 25V | 0.1 µF ±10% 50V Ceramic Capacitor X7R 0603 (1608 Metric) | C3 | CAP0603 | CAP0603_100nF | 1 |  |  |  |  |  |  |  |  | CL10B104KA8NNNC |  |  |  | C1590
 | 0.1uF 16V | 0.1 µF ±20% 16V Ceramic Capacitor X7R 0603 (1608 Metric) | C4 | CAP0603 | C0603C104M4RACTU | 1 |  |  |  | KEMET
Taiyo Yuden | 1uF | CAP CER 1UF 50V X5R 0603 | C5 | CAP0603 | MSASU168SB5105MTNA01 | 1
 | 0.1uF 100V | CAP CER 0.1UF 100V X7R 0603 | C6 | CAP0603 | GRM188R72A104KA35D | 1 |  |  |  | Murata Electronics
 | 22uF 35V | 22 µF ±20% 35V Ceramic Capacitor X5R 1206 (3216 Metric) | C7 | CAP1206 | CAP1206_22uF_35V | 1 |  |  |  |  |  |  |  |  | C3216X5R1V226M160AC
Cal-Chip Electronics, Inc. | 1 µF | CAP0603 X7R 1UF 10% 25V | C8, C19 | CAP 0603_1608 | GMC10X7R105K25NT | 2
Murata Electronics | 10 µF | CAP CER 10UF 50V X5R 0805 | C9 | CAP 0805_2012 | GRM21BR61H106KE43L | 1
Murata Electronics | GCM188R71H104KA57J | CAP CER 0.1UF 50V X7R 0603 | C10, C12, C13, C14, C15, C16 | CAP 0603_1608 | GCM188R71H104KA57J | 6
Murata Electronics | 4.7 µF | CAP CER 4.7UF 50V X7R 0805 | C11 | CAP 0805_2012 | GRM21BZ71H475KE15K | 1
Cal-Chip Electronics, Inc. | 8.2 pF | CAP0402 COG 8.2PF 5% 25V | C17, C18 | CAP 0402_1005 | GMC04CG8R2J25NT | 2
KEMET | 10000 pF | CAP CER 0603 10NF 16V X7R 10% | C20 | CAP 0603_1608 | C0603C103K4RECTU | 1
Cal-Chip Electronics, Inc. | 47pF | 47 pF ±1% 200V Ceramic Capacitor C0G, NP0 0603 (1608 Metric) | C21, C24 | CAPC1608X100N | GMC10CG470F200NT | 2 |  |  |  |  |  |  |  |  |  | GMC10CG470F200NT
Murata Electronics North America | 10uF | CAP CER 10UF 25V X5R 0603 | C22 | 0603_C | CAP1461 | 1 |  |  |  |  |  |  |  |  | GRM188R61E106MA73D
 | 100nF | CAP CER 0.1UF 50V X7R 0603 | C23 | CAP0603 | CAP0603_100nF | 1
Murata Electronics North America | 10uF | CAP CER 10UF 25V X5R 0603 | C25, C26 | CAPC1608X100N | CAP1461 | 2 |  |  |  |  |  |  |  |  | GRM188R61E106MA73D
 | 1uF 16V | Multilayer Ceramic Capacitors MLCC - SMD/SMT 0603 1.0uF 16volts X5R 10% | C27, C33, C43 | CAPC1608X100N | VJ0603G105KXJCW1BC | 3
KEMET | 10000pF | 10000 pF ±10% 16V Ceramic Capacitor X7R 0603 (1608 Metric) | C28, C32, C34, C36, C38, C42 | CAPC1608X100N | C0603C103K4RECTU | 6 | 0603
KEMET | 10pF 50V | 10 pF ±1% 50V Ceramic Capacitor C0G, NP0 0603 (1608 Metric) | C29, C30 | CAPC1608X100N | C0603C100F5GACAUTO | 2
Panasonic Industry | 100uF 25V | 100 µF 25 V Aluminum - Polymer Capacitors Radial, Can - SMD 24mOhm 5000 Hrs @ 105°C | C31 | CAP_25SVPF100M | 25SVPF100M | 1 | C136279
Walsin Technology Corporation | 2.2uF | 2.2 µF ±10% 25V Ceramic Capacitor X5R 0603 (1608 Metric) | C35, C37, C39, C41 | CAPC1608X100N | 0603X225K250CT | 4 | C237194
Vishay Vitramon | 0.1uF 16V | 0.1 µF ±10% 16V Ceramic Capacitor X7R 0603 (1608 Metric) | C40 | CAPC1608X100N | VJ0603Y104KXJAC | 1
Cal-Chip Electronics, Inc. | 150pF 50V | 150 pF ±2% 50V Ceramic Capacitor C0G, NP0 0402 (1005 Metric) | C44, C55 | CAPC1005X04L | GMC04CG151G50NT | 2
Cal-Chip Electronics, Inc. | 10pF 50V | CAP0402 COG 10PF 2% 50V | C45, C48, C50, C54 | CAPC1005X04L | GMC04CG100G50NT | 4
Cal-Chip Electronics, Inc. | 33pF 50V | 33 pF ±1% 50V Ceramic Capacitor C0G, NP0 0402 (1005 Metric) | C46, C52 | CAPC1005X04L | GMC04CG330F50NT | 2
 | 180pF 50V | 180 pF ±1% 50V Ceramic Capacitor C0G, NP0 0402 (1005 Metric) | C47, C53 | CAPC1005X04L | GMC04CG181F50NT | 2
Cal-Chip Electronics, Inc. | 360pF 50V | 360 pF ±5% 50V Ceramic Capacitor C0G, NP0 0402 (1005 Metric) | C49, C51 | CAPC1005X04L | GMC04CG361J50NT | 2
Littelfuse Inc. | SMDJ33CA | 53.3V Clamp 56.3A Ipp Tvs Diode Surface Mount DO-214AB (SMCJ) | D1 | DIONM7959X262N | SMDJ33CA | 1
Lite-On Inc. | LTST-C191KRKT | LED RED CLEAR SMD | D2 | LED0603 | LED_1 | 1 |  |  |  |  |  |  |  |  | LTST-C191KRKT
Lite-On Inc. | LED RED CLEAR SMD | Red 631nm LED Indication - Discrete 2V 0603 (1608 Metric) | D3, D4 | Lite-On_RED_0603 | LTST-C191KRKT_2 | 2 |  |  |  |  |  |  |  |  | LTST-C191KRKT
Littelfuse Inc. | 0452002.MRL | 2 A 125 V 125 V Fuse Board Mount (Cartridge Style Excluded) Surface Mount 2-SMD, Square End Block | F1 | FUSC6127X294N | 0452002.MRL | 1
Murata | BLM21PG121SN1D | Ferrite Bead, 120 Ohm @ 100MHz, 500mA, 250 mOhm Max | FB1, FB2 | INDC2012X11L | FB0402-120R@100M-500mA | 2 |  |  |  |  |  |  |  |  | BLM15AG121SN1D
 | ACT45B-510-2P-TL003 | 51 ÂµH @ 100 kHz 2 Line Common Mode Choke Surface Mount 2.8 kOhms @ 10 MHz 200mA DCR 1Ohm | FL1 | FIL_ACT45B-510-2P-TL003 | ACT45B-510-2P-TL003 | 1 |  |  |  |  |  |  |  |  |  |  | ACT45B-510-2P-TL003
 | BLM18PG221SN1D | 220 Ohms @ 100 MHz 1 Power Line Ferrite Bead 0603 (1608 Metric) 1.4A 100mOhm | FL2 | BEADC1608X95N | BLM18PG221SN1D | 1 |  |  |  |  |  |  |  |  |  |  | BLM18PG221SN1D
 | 0430450400 | Connector Header Through Hole, Right Angle 4 position 0.118" (3.00mm) | J1 | CONN_SD-43045-001_04_MOL | 0430450400 | 1 |  |  |  | MOLEX
 | SWR201-NRTN-S03-SA-WH | Connector | J2 | SHDR3W50P0X200_1X3_790X460X630P | SWR201-NRTN-S03-SA-WH | 1
 | CONN HEADER SMD 10POS 1.27MM | Connector Header Surface Mount 10 position 0.050" (1.27mm) | J3 | Samtec_0_MFG | FTSH-105-01-F-DV-K | 1 |  |  |  |  |  |  |  |  | FTSH-105-01-F-DV-K
 | 61300211821 | 2 Position Receptacle Connector 0.100" (2.54mm) Through Hole Gold | J4 | 61300211821 | 61300211821 | 1 |  |  |  | Würth Elektronik
 | 18uH | 18 µH Semi-Shielded Drum Core, Wirewound Inductor 2.2 A 81mOhm Nonstandard | L1 | WE-LQS_6045 | 74404064180 | 1
 | LQW18CNR47J0HD | Description | L2, L3 | IND_LQW18CN_0H_MUR | LQW18CNR47J0HD | 2
 | BSC028N06NS | MOSFET'ler N-Ch 60V 100A TDSON-8 OptiMOS 3 | M1 | BSC028N06NS | BSC028N06NS | 1
 | RC0603FR-07100KL | RES SMD 100K OHM 1% 1/10W 0603 | R1 | FP-RC0603-0_55-MFG | CMP-2100-03662-2 | 1
 | RES 10K OHM 1% 1/8W 0603 | 10 kOhms ±1% 0.125W, 1/8W Chip Resistor 0603 (1608 Metric) Anti-Sulfur Thin Film | R2 | RES0603 | RES0603_10K_%1_1 | 1 |  |  |  |  |  |  |  |  | RNCP0603FTD10K0 |  |  | MCT06030C1002FP500 | C161803
 | 88.7k | 88.7 kOhms ±1% 0.125W, 1/8W Chip Resistor 0603 (1608 Metric) Automotive AEC-Q200 Thick Film | R3 | RES0603 | CRCW060388K7FKEA | 1
 | 22.1k | 22.1 kOhms ±1% 0.1W, 1/10W Chip Resistor 0603 (1608 Metric) Moisture Resistant Thick Film | R4 | RES0603 | RC0603FR-0722K1L | 1
TE Connectivity Passive Product | 330 Ohms | RES SMD 330 OHM 1% 1/5W 0603 | R5 | RES 0603_1608 | CRGH0603F330R | 1
Stackpole Electronics Inc | 10 kOhms | RES 10K OHM 1% 1/16W 0402 | R6, R7, R8, R9 | RES 0402_1005 | RMCF0402FT10K0 | 4
Stackpole Electronics Inc | 0 Ohms | RES 0 OHM JUMPER 1/16W 0402 | R10 | RES 0402_1005 | RMCF0402ZT0R00 | 1
Stackpole Electronics Inc | 1 kOhms | RES 1K OHM 1% 1/16W 0402 | R11, R12 | RES 0402_1005 | RMCF0402FT1K00 | 2
 | 56 Ohms | 56 Ohms ±1% 0.063W, 1/16W Chip Resistor 0402 (1005 Metric) Automotive AEC-Q200 Thick Film | R13, R14 | RES_0402 | RMCF0402FT56R0 | 2 |  | Stackpole Electronics Inc
 | 330 Ohms | 330 Ohms ±1% 0.063W, 1/16W Chip Resistor 0402 (1005 Metric) Automotive AEC-Q200 Thick Film | R15 | RES_0402 | RMCF0402FT330R | 1 |  |  |  | Stackpole Electronics Inc
Stackpole Electronics Inc | 10 kOhms | RES 10K OHM 0.1% 1/16W 0603 | R16, R17 | RES 0603_1608 | RNCS0603BKE10K0_1 | 2
TE Connectivity Passive Product | 560mOhms | 560 mOhms ±1% 0.125W, 1/8W Chip Resistor 0402 (1005 Metric) Current Sense Thick Film | R18, R19 | RES_0402 | RLP73K1ER56FTDF | 2
 | SMD |  | T1, T2, T3, T4, T5, T6 | TEST_POINT | TP | 6
 | LM74700QDBVRQ1 | OR Controller N+1 ORing Controller N-Channel 1:1 SOT-23-6 | U1 | SOT95P280X145-6N/LM74700QDBVRQ1 | LM74700QDBVRQ1 | 1
 | LMR50410XDBVR | Buck Switching Regulator IC Positive Adjustable 1V 1 Output 1A SOT-23-6 | U2 | SOT95P280X145-6N/ | LMR50410XDBVR | 1 |  |  |  |  |  |  |  |  |  | LMR50410XDBVR
 | AP2112K-3.3TRG1 | Linear Voltage Regulator IC Positive Fixed 1 Output 600mA SOT-25 | U3 | SOT95P285X140-5N | AP2112K-3.3TRG1 | 1 |  |  |  |  |  |  |  |  |  |  | AP2112K-3.3TRG1
 | STM32F103C8T6 | ARM Cortex-M3 32-bit MCU, 64 KB Flash, 20 KB Internal RAM, 37 I/Os, 48-pin LQFP, -40 to 85 degC, Tray | U4 | LQFP48_STM | STM32F103C8T6 | 1 |  |  |  |  |  |  |  |  | STM32F103C8T6 |  |  | STM32F103C8T6 | C8734
 | SN65HVD232DR | 1Mbps Transceiver 3V~3.6V SOIC-8 CAN ICs ROHS | U5 | SOIC8 | SN65HVD232DR | 1 |  |  |  |  |  |  |  |  | SN65HVD232DR |  |  |  | C30530
IXYS Integrated Circuits Division | CPC1014NTR | SSR RELAY SPST-NO 400MA 0-60V | U6 | 4-SOP | CPC1014NTR | 1 |  |  |  |  |  |  |  |  | CPC1014NTR
 | ST25R200-BMET | Powerful general-purpose NFC reader for consumer and industrial applications | U7 | UFQFPN24_STM | ST25R200-BMET | 1
 | CS11337-27.12M | 27.12 MHz ±30ppm Crystal 6pF 60 Ohms 4-SMD, No Lead | U8 | NX2016SA2712MHZEXS00ACS11337 | CS11337-27.12M | 1 |  |  | NDK (NIHON DEMPA KOGYO CO., LTD)
 | ECS-80-8-30Q-VS-TR | 8 MHz Â±30ppm Crystal 8pF 100 Ohms 2-SMD, No Lead | Y1 | XTAL_ECS-80-8-30Q-VS-TR | ECS-80-8-30Q-VS-TR | 1 |  |  |  |  |  |  |  |  |  |  | ECS-80-8-30Q-VS-TR

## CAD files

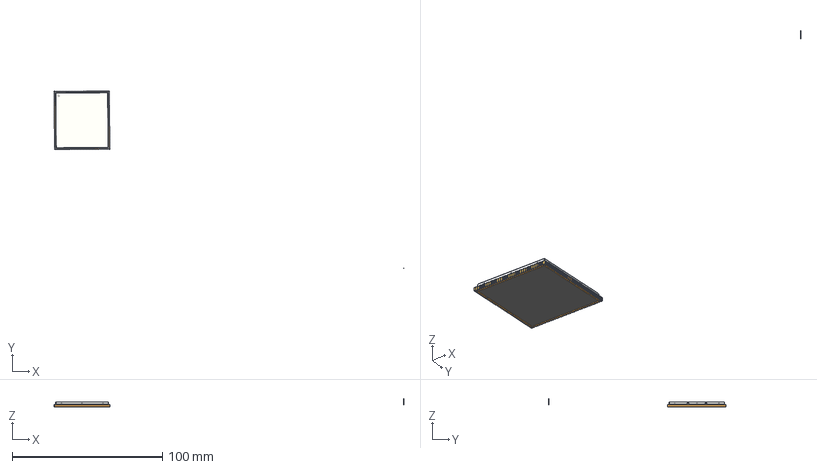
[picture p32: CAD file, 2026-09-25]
MEC/Board_STEP_Models/MAINCTRL_MYIR_MYD-YF13X/myc-yf135-v02_asm.stp
233.2 x 118.2 x 5.43 mm
39X37
MYC-TOP
MYC-BOT
TEMPLATE-A2
TFBGA320
TPAD_020 x 6
R0402-46893_6 x 46
PART6_ASSEM3-1-SOLID2_8 x 10
USER_LIBRARY-0603_CAP-1-SOLID1_ x 10
CUT-EXTRUDE1-58134_6 x 10
WRAP1-58135_6 x 10
NONE-58127_AF0_6 x 79
NONE-58130_AF0_6 x 79
PIN1-20957_2_4
PIN2-20958_2_4
PIN3_2_4
PIN4_2_4
CHIP-20961_2_4
USER_LIBRARY-SOT-23-5_PIN_SOT_S x 5
USER_LIBRARY-SOT-23-5_BODY_SOT2
PRODUCT_1_0_1_1_3 x 3
PRODUCT_1_0_1_2_3 x 3
PRODUCT_1_0_1_3_3 x 3
PRODUCT_1_0_1_4_3 x 3
PRODUCT_1_0_1_5_3 x 3
PRODUCT_1_0_1_6_3 x 3
PRODUCT_1_0_1_7_3 x 3
WSON9_1
_1_AF0_2_4
FBGA96_14X8
PBK
PBZ

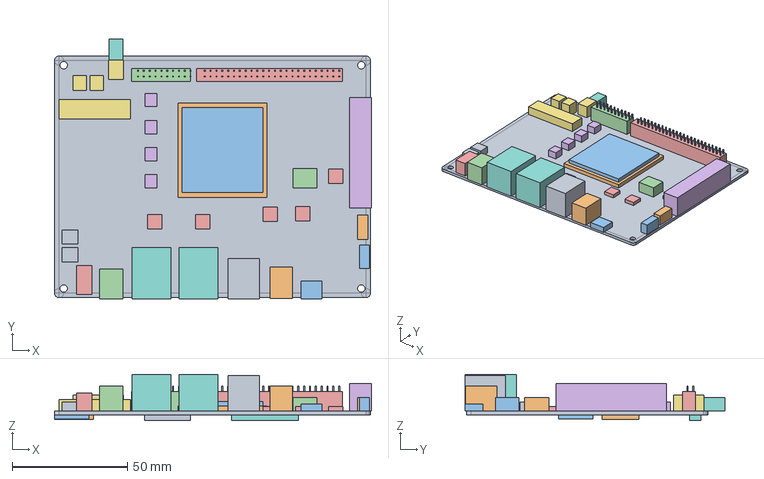
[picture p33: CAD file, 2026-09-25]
MEC/Board_STEP_Models/MAINCTRL_MYIR_MYD-YF13X/MAINCTRL_MYD-YF13X_Provisional_Placement_R1.step
137.7 x 113.1 x 20.1 mm

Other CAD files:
MEC/01_CAD_MODELS/TRAY - WIDTH COMPLIANT.STEP.SLDASM
MEC/AVM-FRAME-MAINASSEMBLY_V4.STEP
MEC/01_CAD_MODELS/60cc ROUND BOTTLE ASSY.STEP.SLDASM
MEC/01_CAD_MODELS/Boards/MAINCTRL_MYD-YF13X_Provisional_Placement_R1.SLDPRT
MEC/01_CAD_MODELS/TRAY - WIDTH COMPLIANT - CONCEPT 2.STEP.SLDASM
MEC/01_CAD_MODELS/LAYER SUB-ASSEMBLY-NEWLANE_KEY HOLE STUD-1.STEP.SLDASM
MEC/01_CAD_MODELS/AVM-FRAME-MAINASSEMBLY_V4.STEP.SLDASM
MEC/01_CAD_MODELS/SS ACHS WITH LW(M5X16).STEP-2.SLDASM
MEC/01_CAD_MODELS/STEPPER MOTOR MOUNTING SHEET 1 WITH INSERT.STEP.SLDASM
MEC/01_CAD_MODELS/SS ACHS WITH LW(M5X16).STEP-3.SLDASM
MEC/01_CAD_MODELS/TRAY - WIDTH COMPLIANT.STEP-3.SLDASM
MEC/01_CAD_MODELS/TRAY - WIDTH COMPLIANT - CONCEPT 2-2.STEP.SLDASM
MEC/01_CAD_MODELS/120cc ROUND BOTTLE ASSY.STEP-2.SLDASM
MEC/01_CAD_MODELS/MINI LM GUIDE ASSEMBLY-2.STEP.SLDASM
MEC/01_CAD_MODELS/SS ACHS WITH LW(M5X16).STEP-9.SLDASM
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

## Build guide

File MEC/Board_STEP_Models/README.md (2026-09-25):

# Board STEP models

Blackocean Technologies / Adherent360 APDU

Mechanical integration handoff folder. Models are available, but they are not all verified manufacturer models or production PCB exports.

- `MAINCTRL_MYIR_MYD-YF13X/`: off-the-shelf MYIR central controller, 1 unit.
- `IOCTRL_Waveshare_ESP32-S3-ETH-8DI-8RO/`: off-the-shelf relay and digital input module, 2 identical units (IOCTRL-01, IOCTRL-02). One model is sufficient for both placements; reserve cabinet space and cable clearance for two.
- `SYSCTRL_Custom/`: custom machine controller, 1 PCB assembly. Export the STEP assembly from the PCB design when available.
- `LANECTRL_Custom/`: custom row controller, 10 identical PCB assemblies. One board model is sufficient for the ten placements. Rocker switches are on this board; lane LEDs connect through 2-pin headers on the board. No separate LANEPANEL.

Store `.step` or `.stp` models in the corresponding folder. For purchased products, record the source URL, exact product variant, and model revision alongside the file. Indicate whether connectors and the enclosure are included, so the mechanical team can check mounting and cable clearance.

## Current model status

- MAINCTRL and IOCTRL have reconstructed `Provisional_Placement_R1.step` models with notes and geometry-validation results. Estimated holes and connector heights are not fabrication dimensions.
- MYIR `myc-yf135-v02_asm.stp` is a module model, not the complete MYD-YF13X carrier assembly.
- LANECTRL: the current model is `../HW_ADHERENT_LANECTRL_R1/HW_ADHERENT_LANECTRL_R1(Variant of HW_ADHERENT_LANECTRL_R1).step`, exported from the routed R1 PCB on 2026-09-25 (504 × 60 mm, 4-layer, rocker switches and LED headers on one side, all SMD on the other, 8 × M3 holes). `LANECTRL_Custom/HW_ADHERENT_LANECTRL_R1.step` is an earlier export; replace it or ignore it. Fit to the front-bracket DWG remains to be verified.
- SYSCTRL requires a STEP assembly from the actual PCB design.
- IOCTRL's reconstruction used a PoE-variant image; fit to the selected non-PoE variant remains open.

No RAR bundle is maintained. Use the individual model files and notes.

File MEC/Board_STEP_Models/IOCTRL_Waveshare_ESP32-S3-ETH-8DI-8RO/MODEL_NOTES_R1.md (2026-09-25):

# IOCTRL provisional placement model R1

Blackocean Technologies / Adherent360 APDU

This is a simplified, locally reconstructed CAD model, not a Waveshare-supplied model. Use it for preliminary cabinet placement only. Do not manufacture or drill mounting parts from it.

## Reference and dimensions

Reference: the user-supplied dimension image, labelled ESP32-S3-POE-ETH-8DI-8RO. The project selects ESP32-S3-ETH-8DI-8RO (non-PoE, RS485). Mechanical equivalence is unverified.

- Overall nominal envelope: 175 x 90 x 40 mm.
- Base thickness: 10 mm.
- Upper enclosure width: 155 mm, interpreted from the image dimension. Confirm its exact datum with the manufacturer.
- Vertical mounting feature centre spacing: 70 mm, with 10 mm end offsets.
- Side mounting feature centre offset: 5 mm, interpreted symmetrically from the image. Horizontal spacing therefore assumed 165 mm; this is not independently confirmed.

## Estimated and omitted geometry

- Four 6 x 4.5 mm mounting slots are estimated visual features. Slot diameter/length were not supplied.
- Enclosure wall structure, cover, terminal recesses, connector sizes and connector positions are approximate.
- Internal PCB, components, fasteners, DIN-rail clip, SMA connector and antenna are omitted because dimensioned geometry was not supplied.
- The nominal envelope does not represent cable bend space or connector/antenna protrusions. Reserve these separately after checking the actual hardware.

## Files and validation

- IOCTRL_Provisional_Placement_R1.step: separate solid parts, millimetres.
- IOCTRL_Provisional_Placement_R1.svg: isometric preview; colours are illustrative.
- build_ocp_R1.py: reproducible OpenCascade source using cadquery-ocp.
- validation_R1.json: STEP reimport validity and bounding-box check.

Origin: lower corner of the nominal base. X = 175 mm length, Y = 90 mm width, Z = 40 mm height. Replace with the manufacturer model once available.

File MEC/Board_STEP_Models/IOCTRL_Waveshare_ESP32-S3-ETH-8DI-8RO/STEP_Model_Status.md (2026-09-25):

# IOCTRL STEP model status

Product: Waveshare ESP32-S3-ETH-8DI-8RO, RS485 version, standard Ethernet port.
Checked: 2026-09-21.

No publicly downloadable manufacturer STEP/STP model was found. The official wiki includes a dimension drawing, but its Resources section does not list a 3D model.

A locally reconstructed provisional placement model is provided as `IOCTRL_Provisional_Placement_R1.step`. This is not a downloaded manufacturer model. Read `MODEL_NOTES_R1.md` for assumptions, missing geometry and the PoE/non-PoE variant limitation.

Sources:
- Product: https://www.waveshare.com/esp32-s3-eth-8di-8ro.htm
- Documentation and dimension drawing: https://www.waveshare.com/wiki/ESP32-S3-ETH-8DI-8RO#Dimensions
- Manufacturer support: https://service.waveshare.com/

Suggested request to the manufacturer (not sent):

Please provide a STEP or STP mechanical assembly model for the ESP32-S3-ETH-8DI-8RO, RS485 version with the standard Ethernet port. We need the complete assembly including the ABS enclosure, 35 mm DIN-rail mounting clip, terminal blocks and connector projections for cabinet integration. Please identify the applicable hardware/enclosure revision. A separate populated PCB model would also be useful. We do not need the CAN (-C) or PoE variant.

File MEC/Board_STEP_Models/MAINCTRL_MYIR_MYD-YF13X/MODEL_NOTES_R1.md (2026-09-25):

# MYIR MYD-YF13X provisional placement model R1

Blackocean Technologies / Adherent360 APDU

Reconstructed from the three user-supplied images: dimensioned base-board top view, populated top photograph and bottom photograph. The reference board is marked MYB-YF13X-V02. This is not manufacturer CAD and does not establish the exact populated ordering variant.

## Confirmed from the dimension drawing

- PCB outline: 137.29 x 105 mm.
- Units: millimetres.

## Assumptions

- PCB thickness 1.6 mm and corner radius 2 mm.
- Four mounting holes: diameter 3.2 mm, centres 4 mm from adjacent board edges. These are estimated from the images; do not use them to drill mounting hardware.
- Connector XY positions and footprints are scaled from the top-view drawing. All connector and component heights are estimates.
- RJ45 bodies are 16 mm above the PCB top, dual USB 15.5 mm, field terminal block 12 mm, DC jack/audio 11 mm, expansion header including exposed pins 11 mm, SoM shield 4.3 mm.
- Bottom-side FFC connectors extend 2.5 mm below the PCB; SIM and microSD socket envelopes extend 2.0 and 1.8 mm. Their locations are estimated from the mirrored bottom photograph.
- Connector cavities, screw terminals, mating hardware, solder tails, most small components and cable bend space are not modelled. Header pins are illustrative, not an electrical pin-count reference.
- The empty mini-PCIe area has no fitted modem model. SIM socket geometry represents the physical board connector, not a cellular requirement.
- SMA geometry is a simplified connector projection; no external antenna is included.

## Use and files

Use for preliminary placement only. Verify hole locations, component height, underside clearance and connector access against actual hardware or manufacturer drawings before releasing mounting parts.

Origin is the lower-left corner in the supplied top view, on the PCB bottom surface. X runs right, Y runs towards the expansion headers, Z is positive above the PCB. Bottom-side components have negative Z.

- `MAINCTRL_MYD-YF13X_Provisional_Placement_R1.step`: independent solid components; millimetres.
- `MAINCTRL_MYD-YF13X_Provisional_Placement_R1.png`: preview rendered from CAD geometry; colours are illustrative.
- `build_ocp_R1.py`: reproducible OpenCascade source (cadquery-ocp, NumPy, Pillow).
- `validation_R1.json`: STEP reimport validity and bounding-box measurements. Assembly dimensions include estimated connector projections and must not be mistaken for verified product dimensions.

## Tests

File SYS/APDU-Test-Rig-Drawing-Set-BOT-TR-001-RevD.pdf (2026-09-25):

## 1. POWER INPUT AND DISTRIBUTION

## LRS-200-24

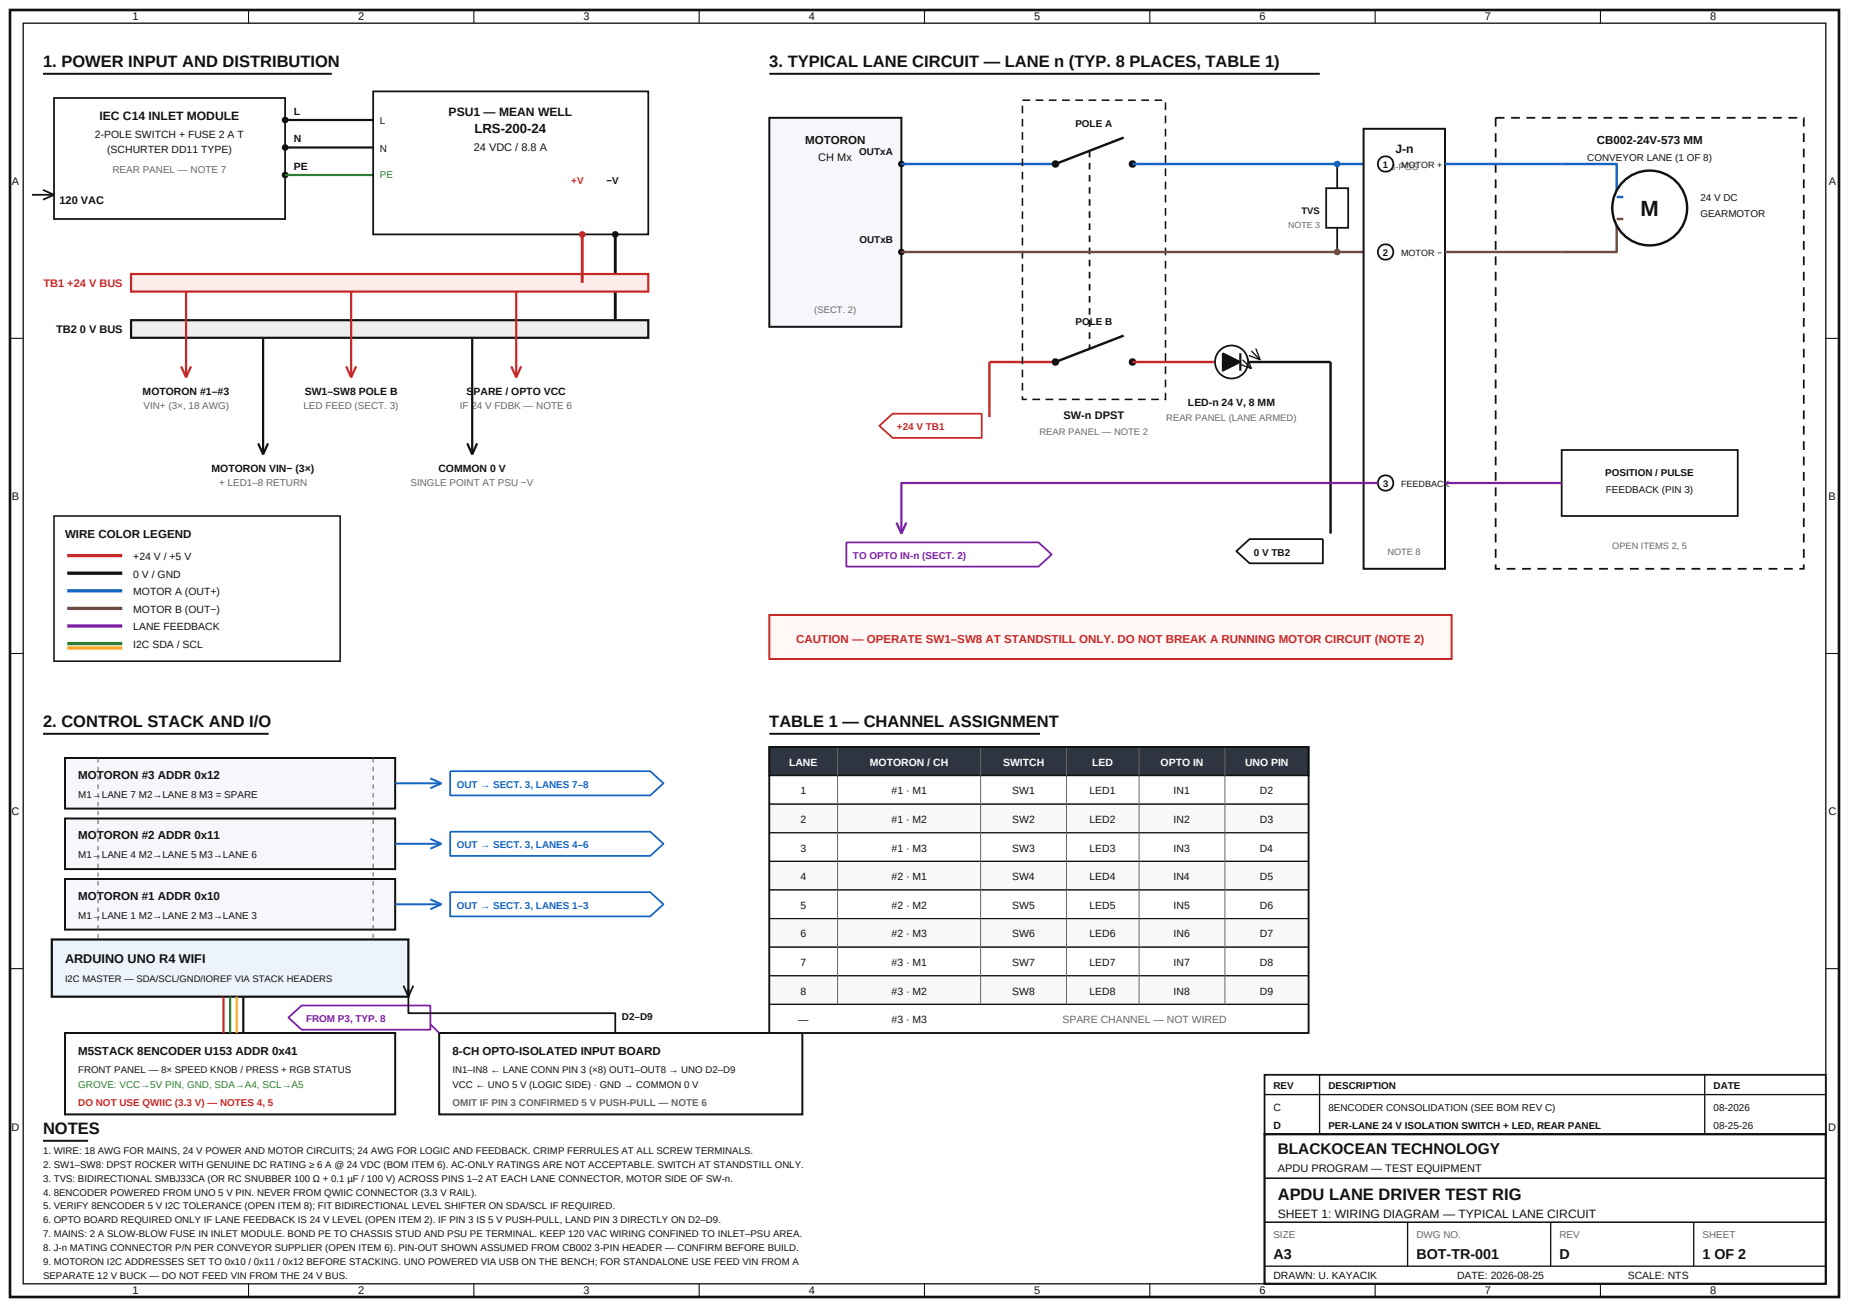
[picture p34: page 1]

3. TYPICAL LANE CIRCUIT — LANE n (TYP. 8 PLACES, TABLE 1)

LED-n 24 V, 8 MM
REAR PANEL (LANE ARMED)

COMMON 0 V
SINGLE POINT AT PSU −V

NOTE 8 TO OPTO IN-n (SECT. 2)

CAUTION — OPERATE SW1–SW8 AT STANDSTILL ONLY. DO NOT BREAK A RUNNING MOTOR CIRCUIT (NOTE 2)

I2C MASTER — SDA/SCL/GND/IOREF VIA STACK HEADERS

M5STACK 8ENCODER U153 ADDR 0x41
FRONT PANEL — 8× SPEED KNOB / PRESS + RGB STATUS
GROVE: VCC→5V PIN, GND, SDA→A4, SCL→A5
DO NOT USE QWIIC (3.3 V) — NOTES 4, 5
NOTES

8-CH OPTO-ISOLATED INPUT BOARD
IN1–IN8 ← LANE CONN PIN 3 (×8) OUT1–OUT8 → UNO D2–D9
VCC ← UNO 5 V (LOGIC SIDE) · GND → COMMON 0 V
OMIT IF PIN 3 CONFIRMED 5 V PUSH-PULL — NOTE 6

BLACKOCEAN TECHNOLOGY
APDU PROGRAM — TEST EQUIPMENT
APDU LANE DRIVER TEST RIG
SHEET 1: WIRING DIAGRAM — TYPICAL LANE CIRCUIT

1. WIRE: 18 AWG FOR MAINS, 24 V POWER AND MOTOR CIRCUITS; 24 AWG FOR LOGIC AND FEEDBACK. CRIMP FERRULES AT ALL SCREW TERMINALS.
2. SW1–SW8: DPST ROCKER WITH GENUINE DC RATING ≥ 6 A @ 24 VDC (BOM ITEM 6). AC-ONLY RATINGS ARE NOT ACCEPTABLE. SWITCH AT STANDSTILL ONLY.
3. TVS: BIDIRECTIONAL SMBJ33CA (OR RC SNUBBER 100 Ω + 0.1 µF / 100 V) ACROSS PINS 1–2 AT EACH LANE CONNECTOR, MOTOR SIDE OF SW-n.
4. 8ENCODER POWERED FROM UNO 5 V PIN. NEVER FROM QWIIC CONNECTOR (3.3 V RAIL).
5. VERIFY 8ENCODER 5 V I2C TOLERANCE (OPEN ITEM 8); FIT BIDIRECTIONAL LEVEL SHIFTER ON SDA/SCL IF REQUIRED.
6. OPTO BOARD REQUIRED ONLY IF LANE FEEDBACK IS 24 V LEVEL (OPEN ITEM 2). IF PIN 3 IS 5 V PUSH-PULL, LAND PIN 3 DIRECTLY ON D2–D9.
7. MAINS: 2 A SLOW-BLOW FUSE IN INLET MODULE. BOND PE TO CHASSIS STUD AND PSU PE TERMINAL. KEEP 120 VAC WIRING CONFINED TO INLET–PSU AREA.
8. J-n MATING CONNECTOR P/N PER CONVEYOR SUPPLIER (OPEN ITEM 6). PIN-OUT SHOWN ASSUMED FROM CB002 3-PIN HEADER — CONFIRM BEFORE BUILD.
9. MOTORON I2C ADDRESSES SET TO 0x10 / 0x11 / 0x12 BEFORE STACKING. UNO POWERED VIA USB ON THE BENCH; FOR STANDALONE USE FEED VIN FROM A
SEPARATE 12 V BUCK — DO NOT FEED VIN FROM THE 24 V BUS.

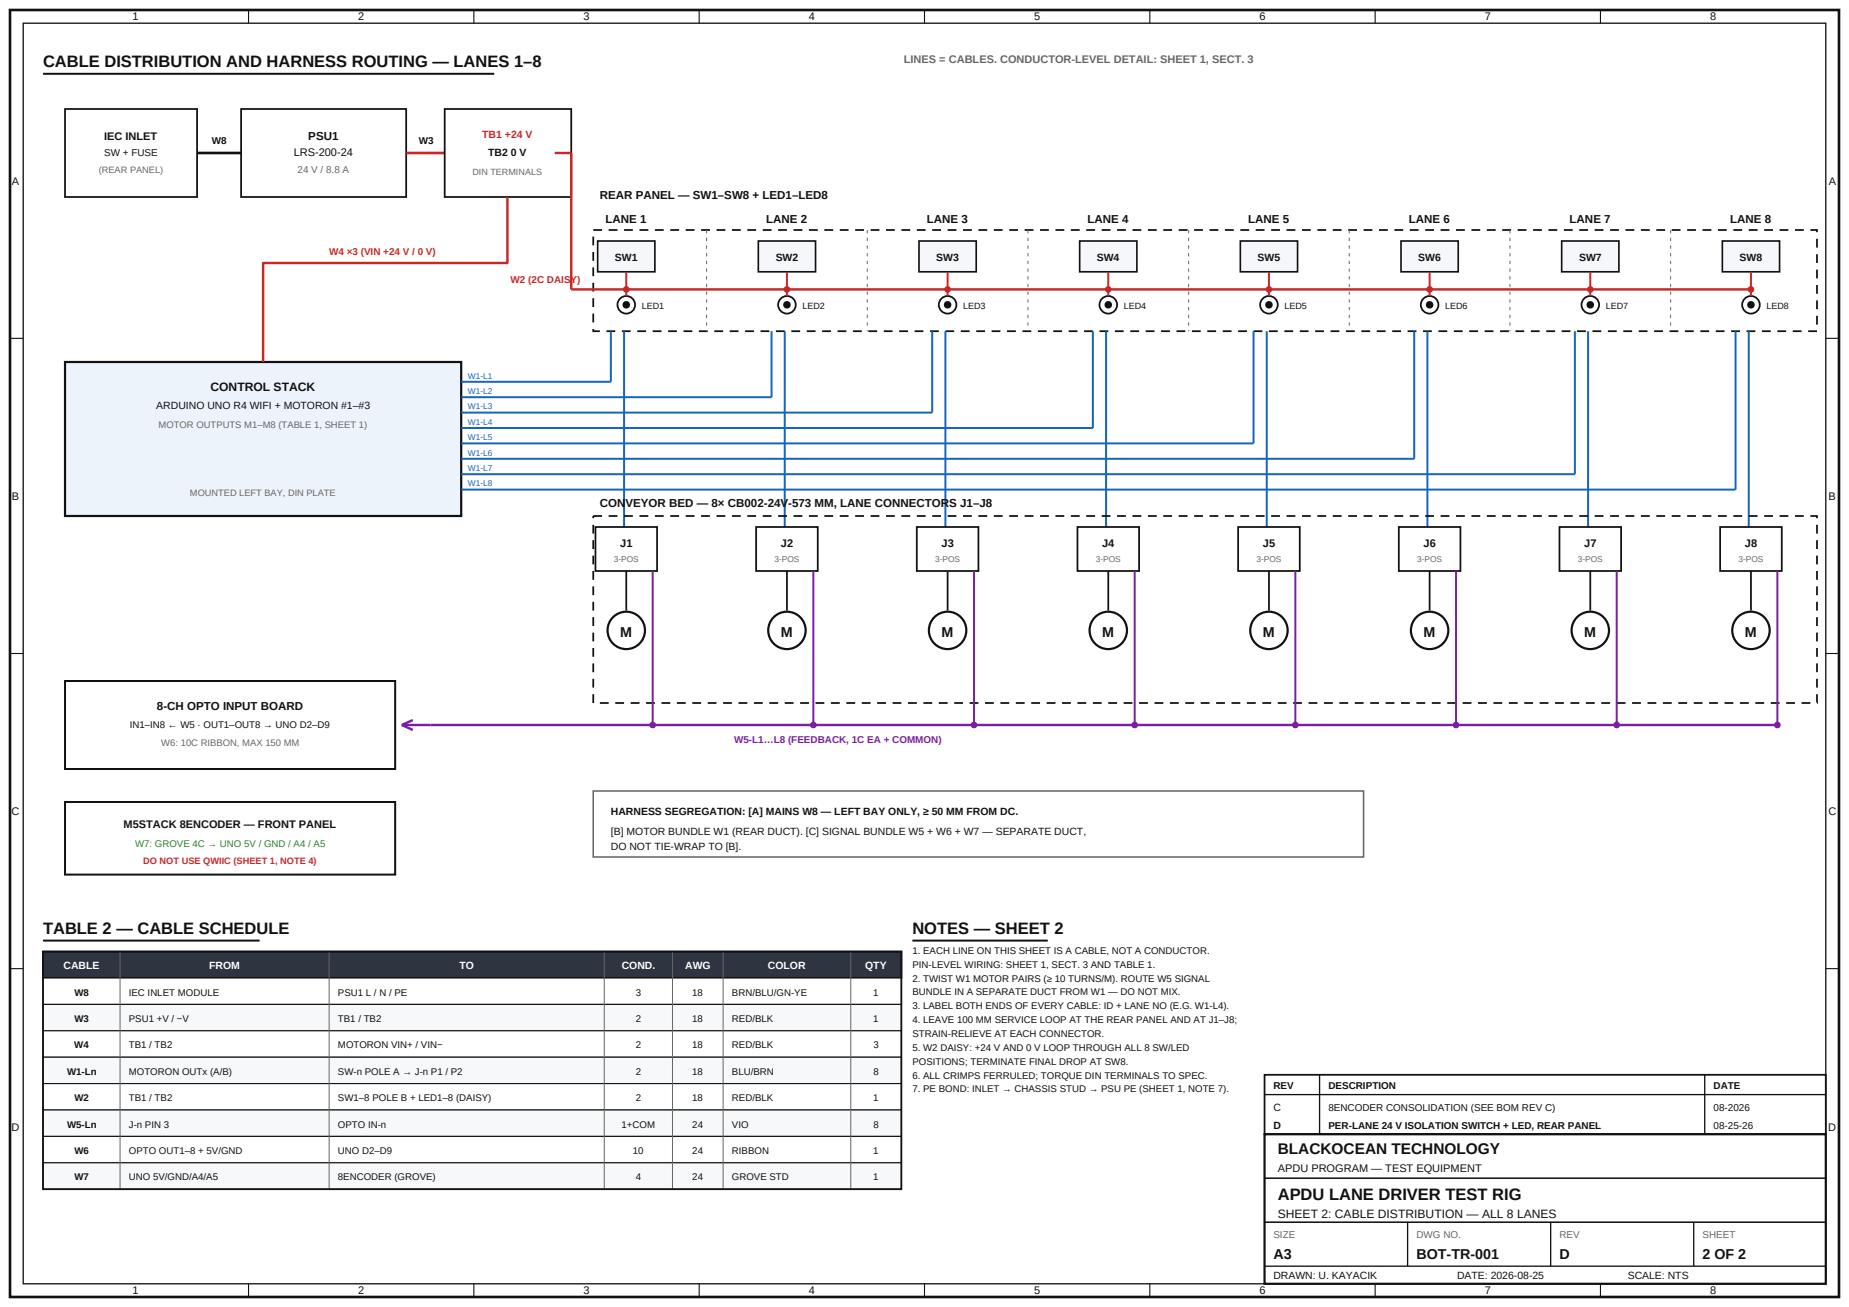
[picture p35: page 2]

ARDUINO UNO R4 WIFI + MOTORON #1–#3

MOTOR OUTPUTS M1–M8 (TABLE 1, SHEET 1)

MOUNTED LEFT BAY, DIN PLATE

CONVEYOR BED — 8× CB002-24V-573 MM, LANE CONNECTORS J1–J8

8-CH OPTO INPUT BOARD
IN1–IN8 ← W5 · OUT1–OUT8 → UNO D2–D9

HARNESS SEGREGATION: [A] MAINS W8 — LEFT BAY ONLY, ≥ 50 MM FROM DC.
[B] MOTOR BUNDLE W1 (REAR DUCT). [C] SIGNAL BUNDLE W5 + W6 + W7 — SEPARATE DUCT,
DO NOT TIE-WRAP TO [B].

M5STACK 8ENCODER — FRONT PANEL
W7: GROVE 4C → UNO 5V / GND / A4 / A5
DO NOT USE QWIIC (SHEET 1, NOTE 4)

1. EACH LINE ON THIS SHEET IS A CABLE, NOT A CONDUCTOR.
PIN-LEVEL WIRING: SHEET 1, SECT. 3 AND TABLE 1.
2. TWIST W1 MOTOR PAIRS (≥ 10 TURNS/M). ROUTE W5 SIGNAL
BUNDLE IN A SEPARATE DUCT FROM W1 — DO NOT MIX.
3. LABEL BOTH ENDS OF EVERY CABLE: ID + LANE NO (E.G. W1-L4).
4. LEAVE 100 MM SERVICE LOOP AT THE REAR PANEL AND AT J1–J8;
STRAIN-RELIEVE AT EACH CONNECTOR.
5. W2 DAISY: +24 V AND 0 V LOOP THROUGH ALL 8 SW/LED
POSITIONS; TERMINATE FINAL DROP AT SW8.
6. ALL CRIMPS FERRULED; TORQUE DIN TERMINALS TO SPEC.
7. PE BOND: INLET → CHASSIS STUD → PSU PE (SHEET 1, NOTE 7).

BLACKOCEAN TECHNOLOGY
APDU PROGRAM — TEST EQUIPMENT
APDU LANE DRIVER TEST RIG
SHEET 2: CABLE DISTRIBUTION — ALL 8 LANES

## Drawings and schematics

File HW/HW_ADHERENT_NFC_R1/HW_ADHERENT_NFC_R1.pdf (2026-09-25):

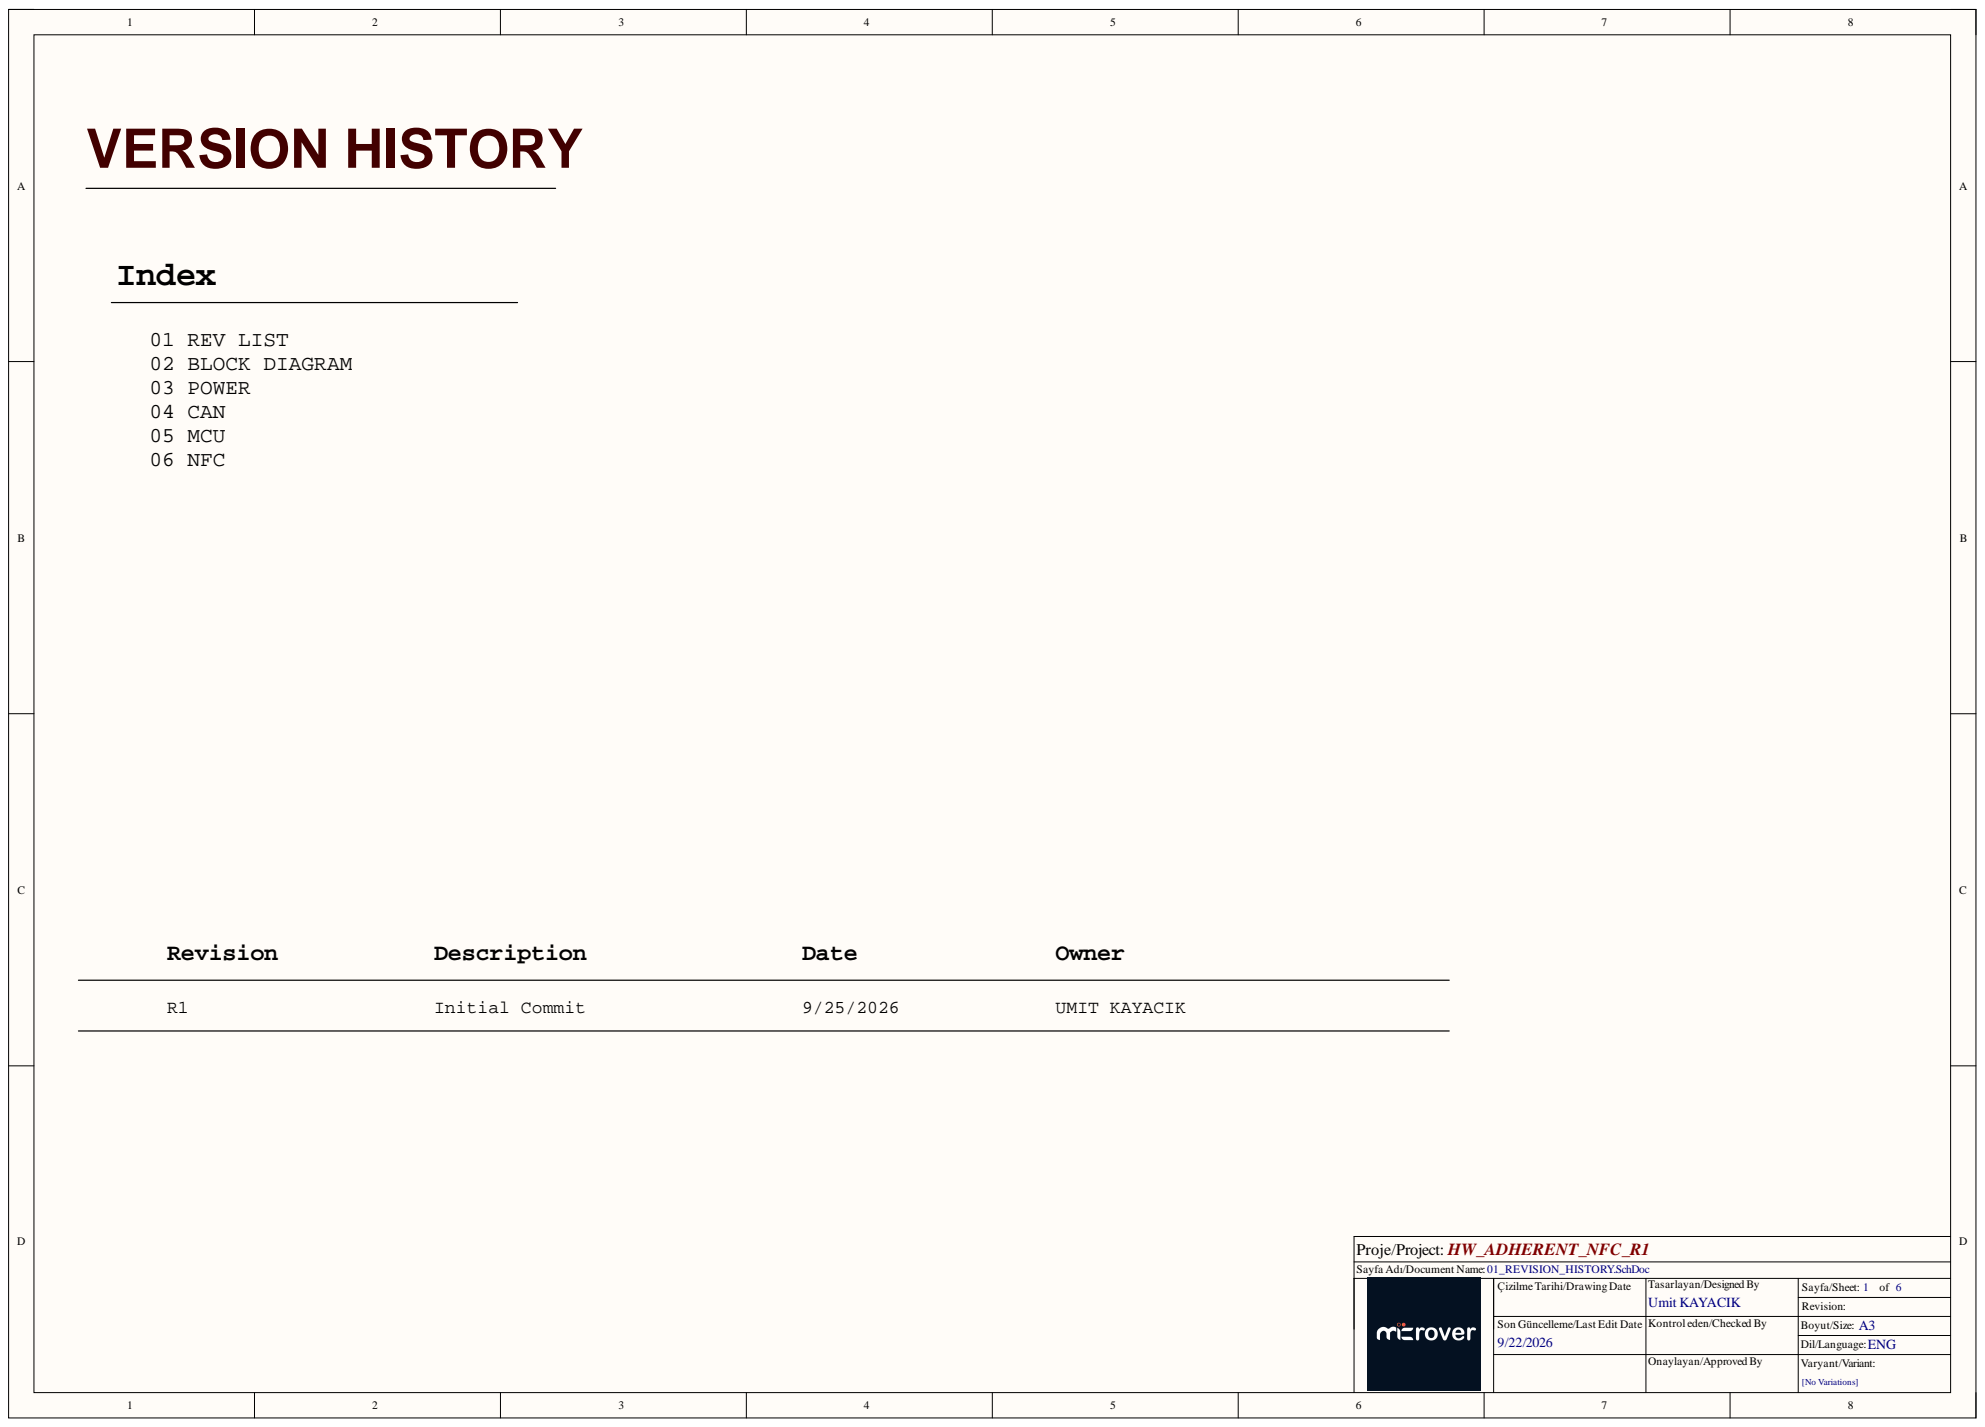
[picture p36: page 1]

Sayfa Adı/Document Name:

Son Güncelleme/Last Edit Date

Kontrol eden/Checked By

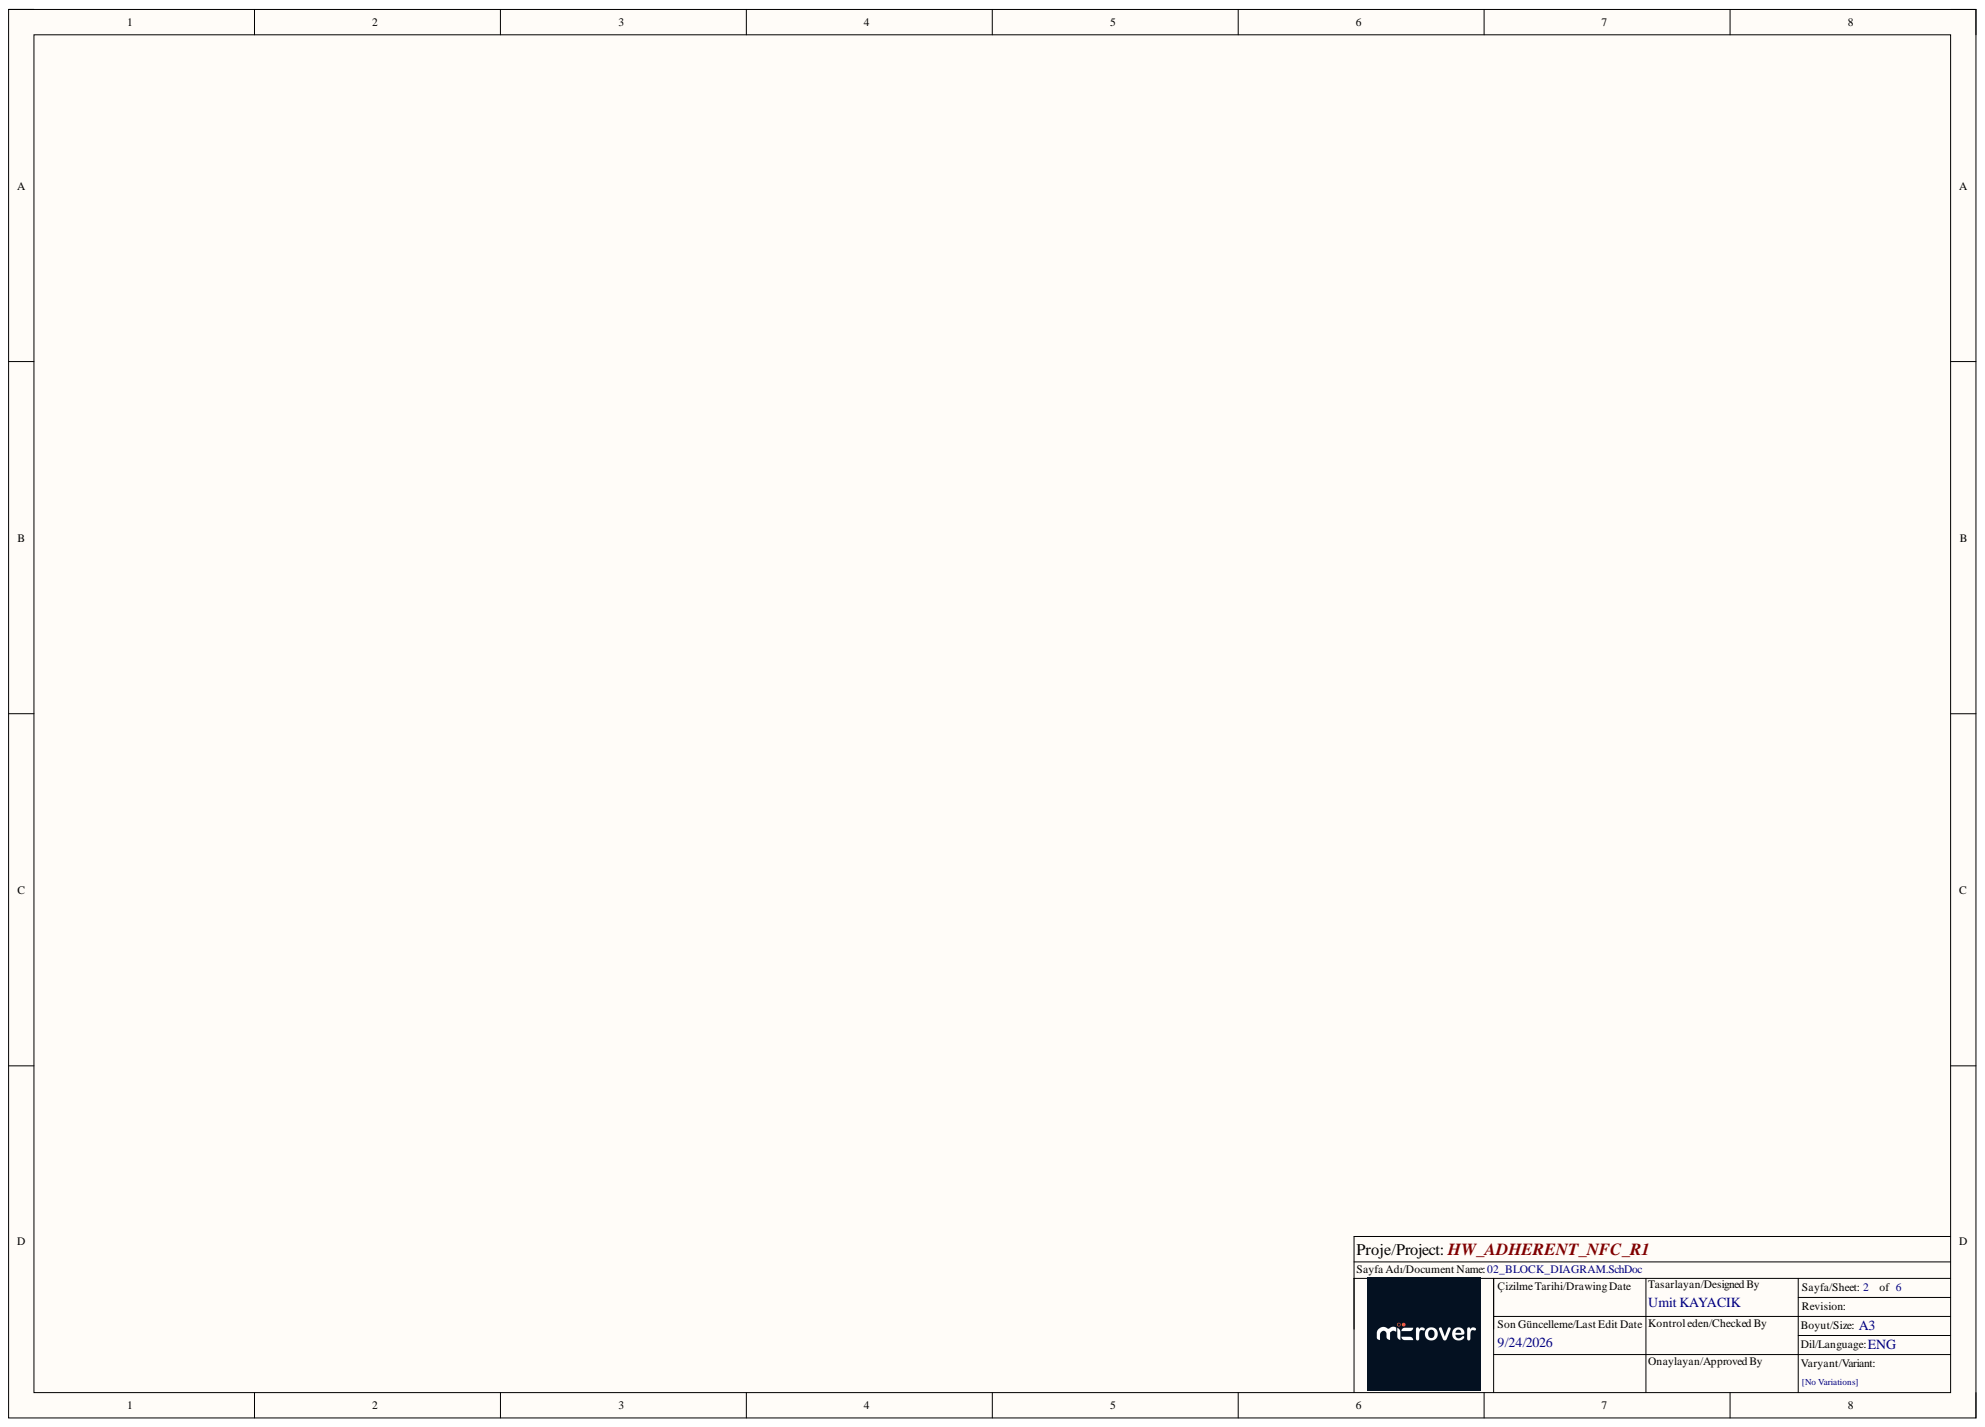
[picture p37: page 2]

Sayfa Adı/Document Name:

Son Güncelleme/Last Edit Date

Kontrol eden/Checked By

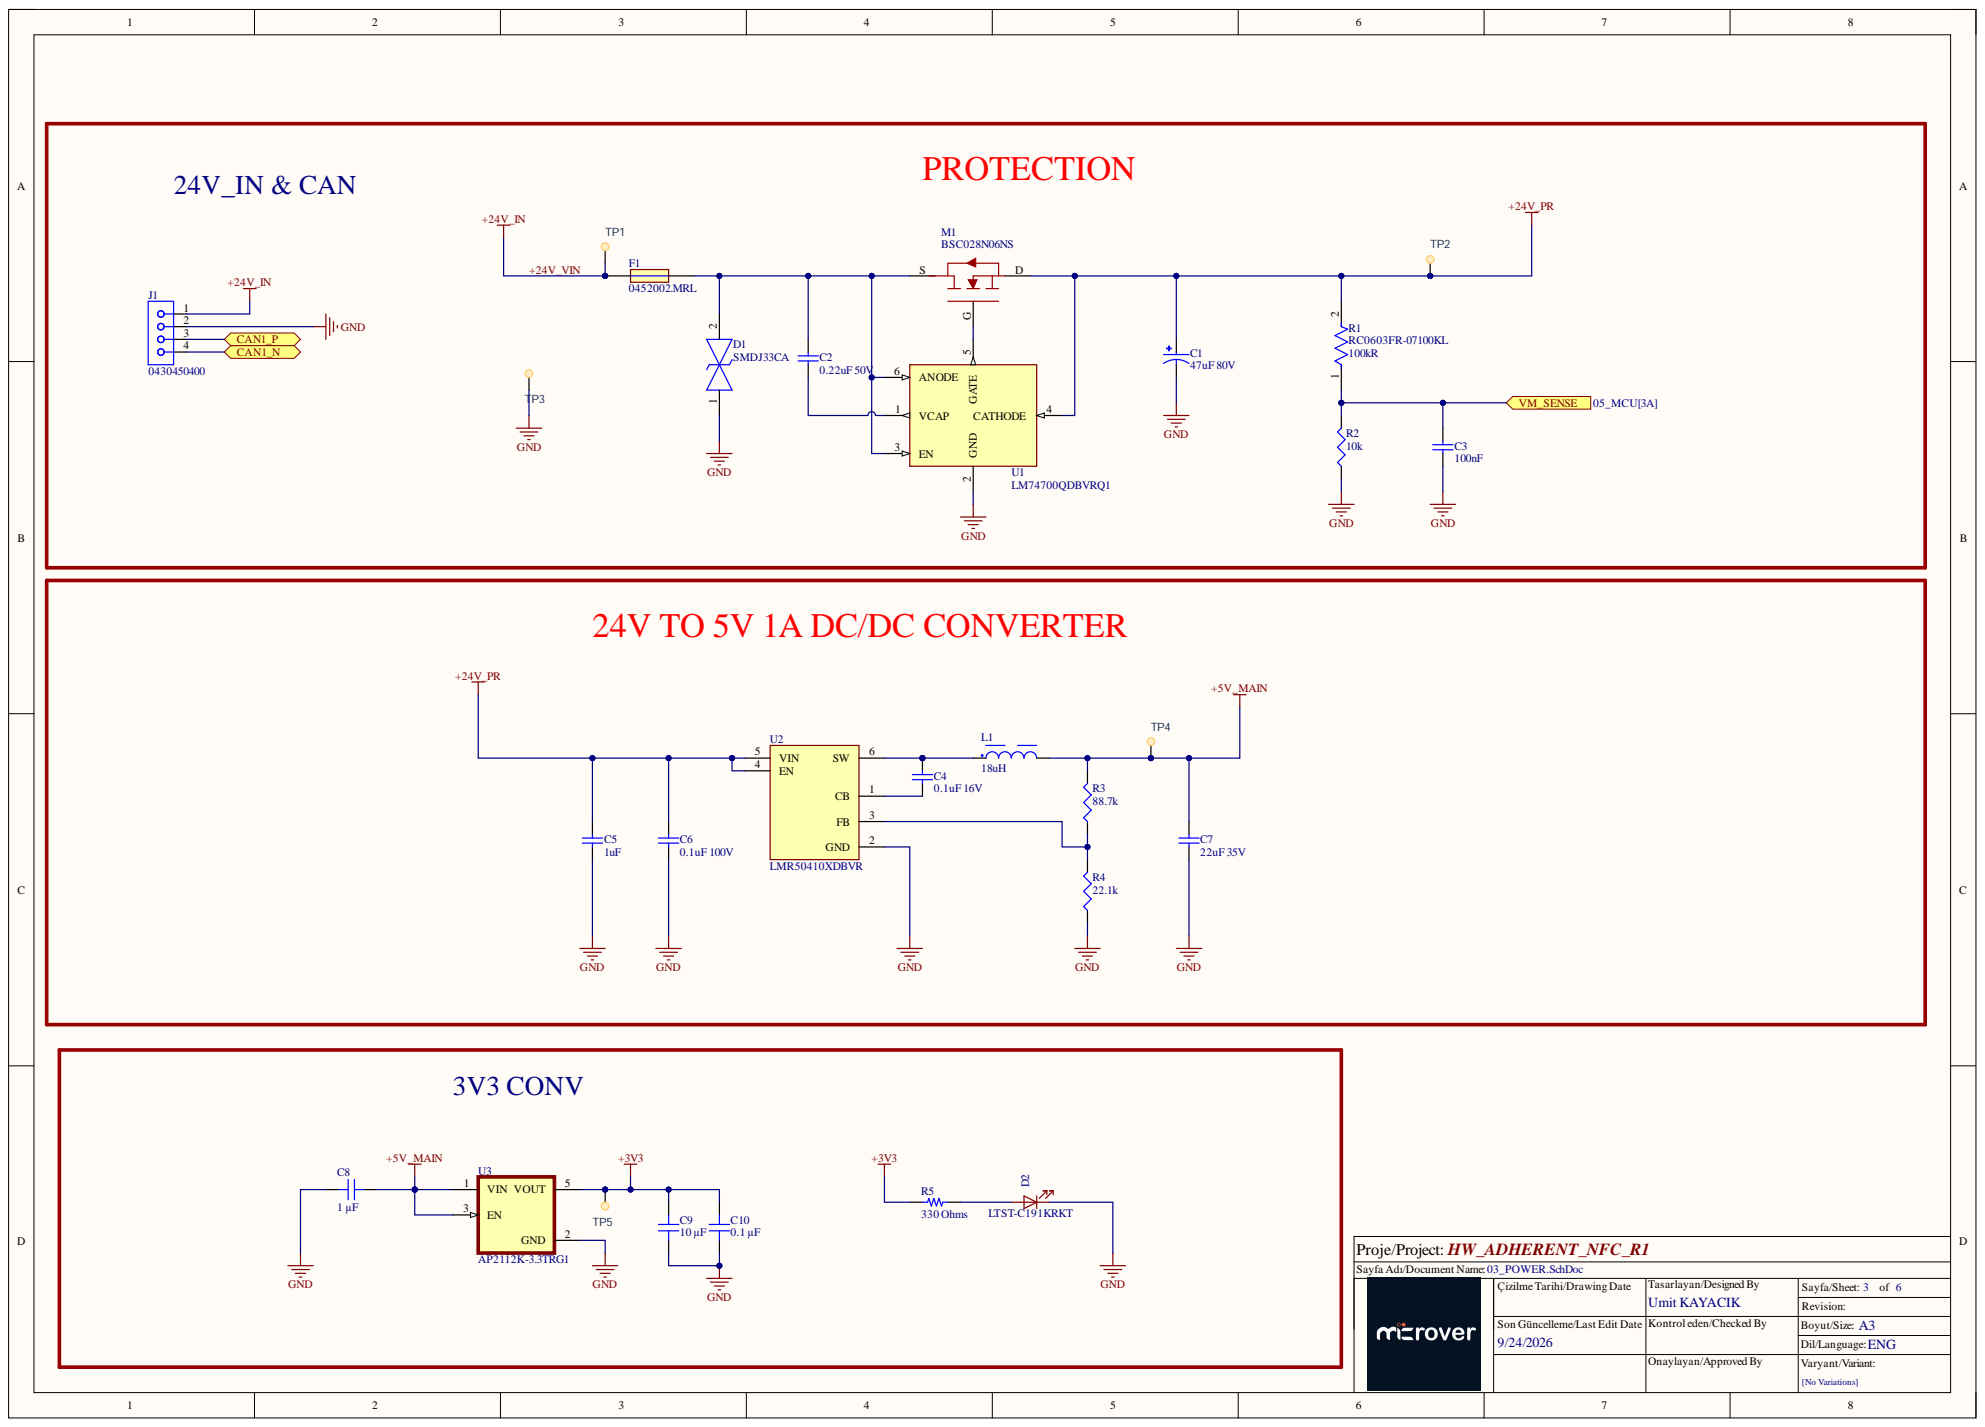
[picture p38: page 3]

24V TO 5V 1A DC/DC CONVERTER

Sayfa Adı/Document Name:

Son Güncelleme/Last Edit Date

Kontrol eden/Checked By

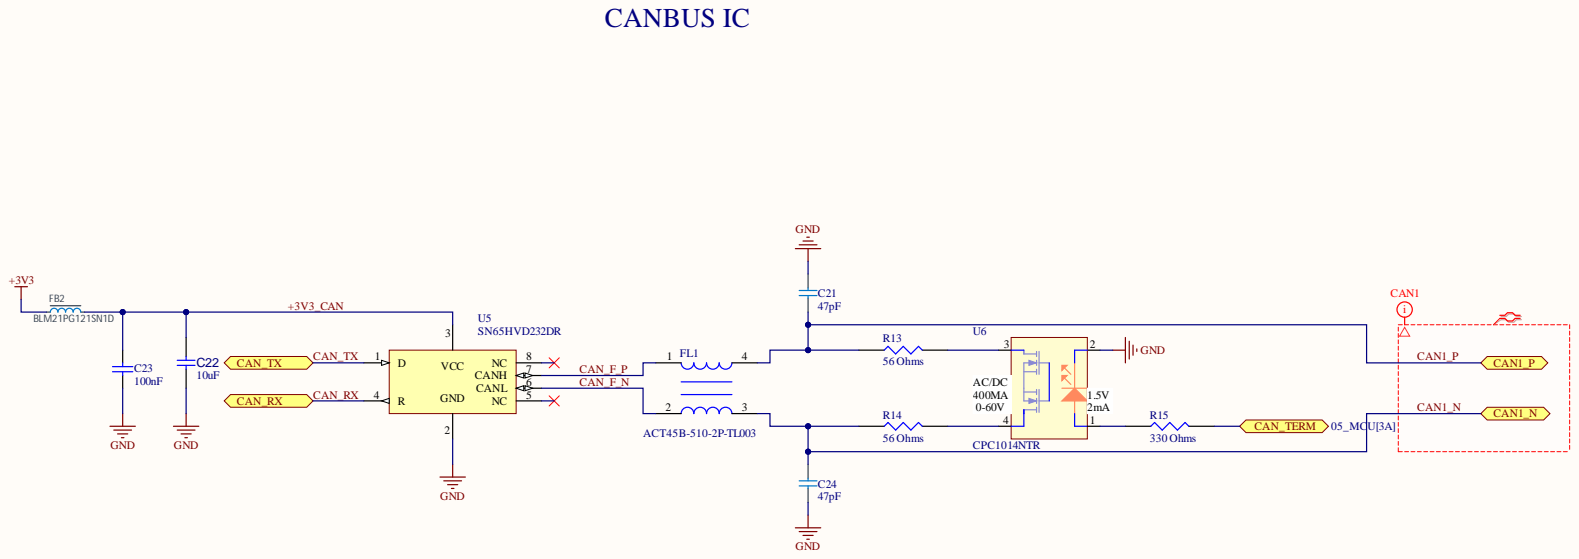
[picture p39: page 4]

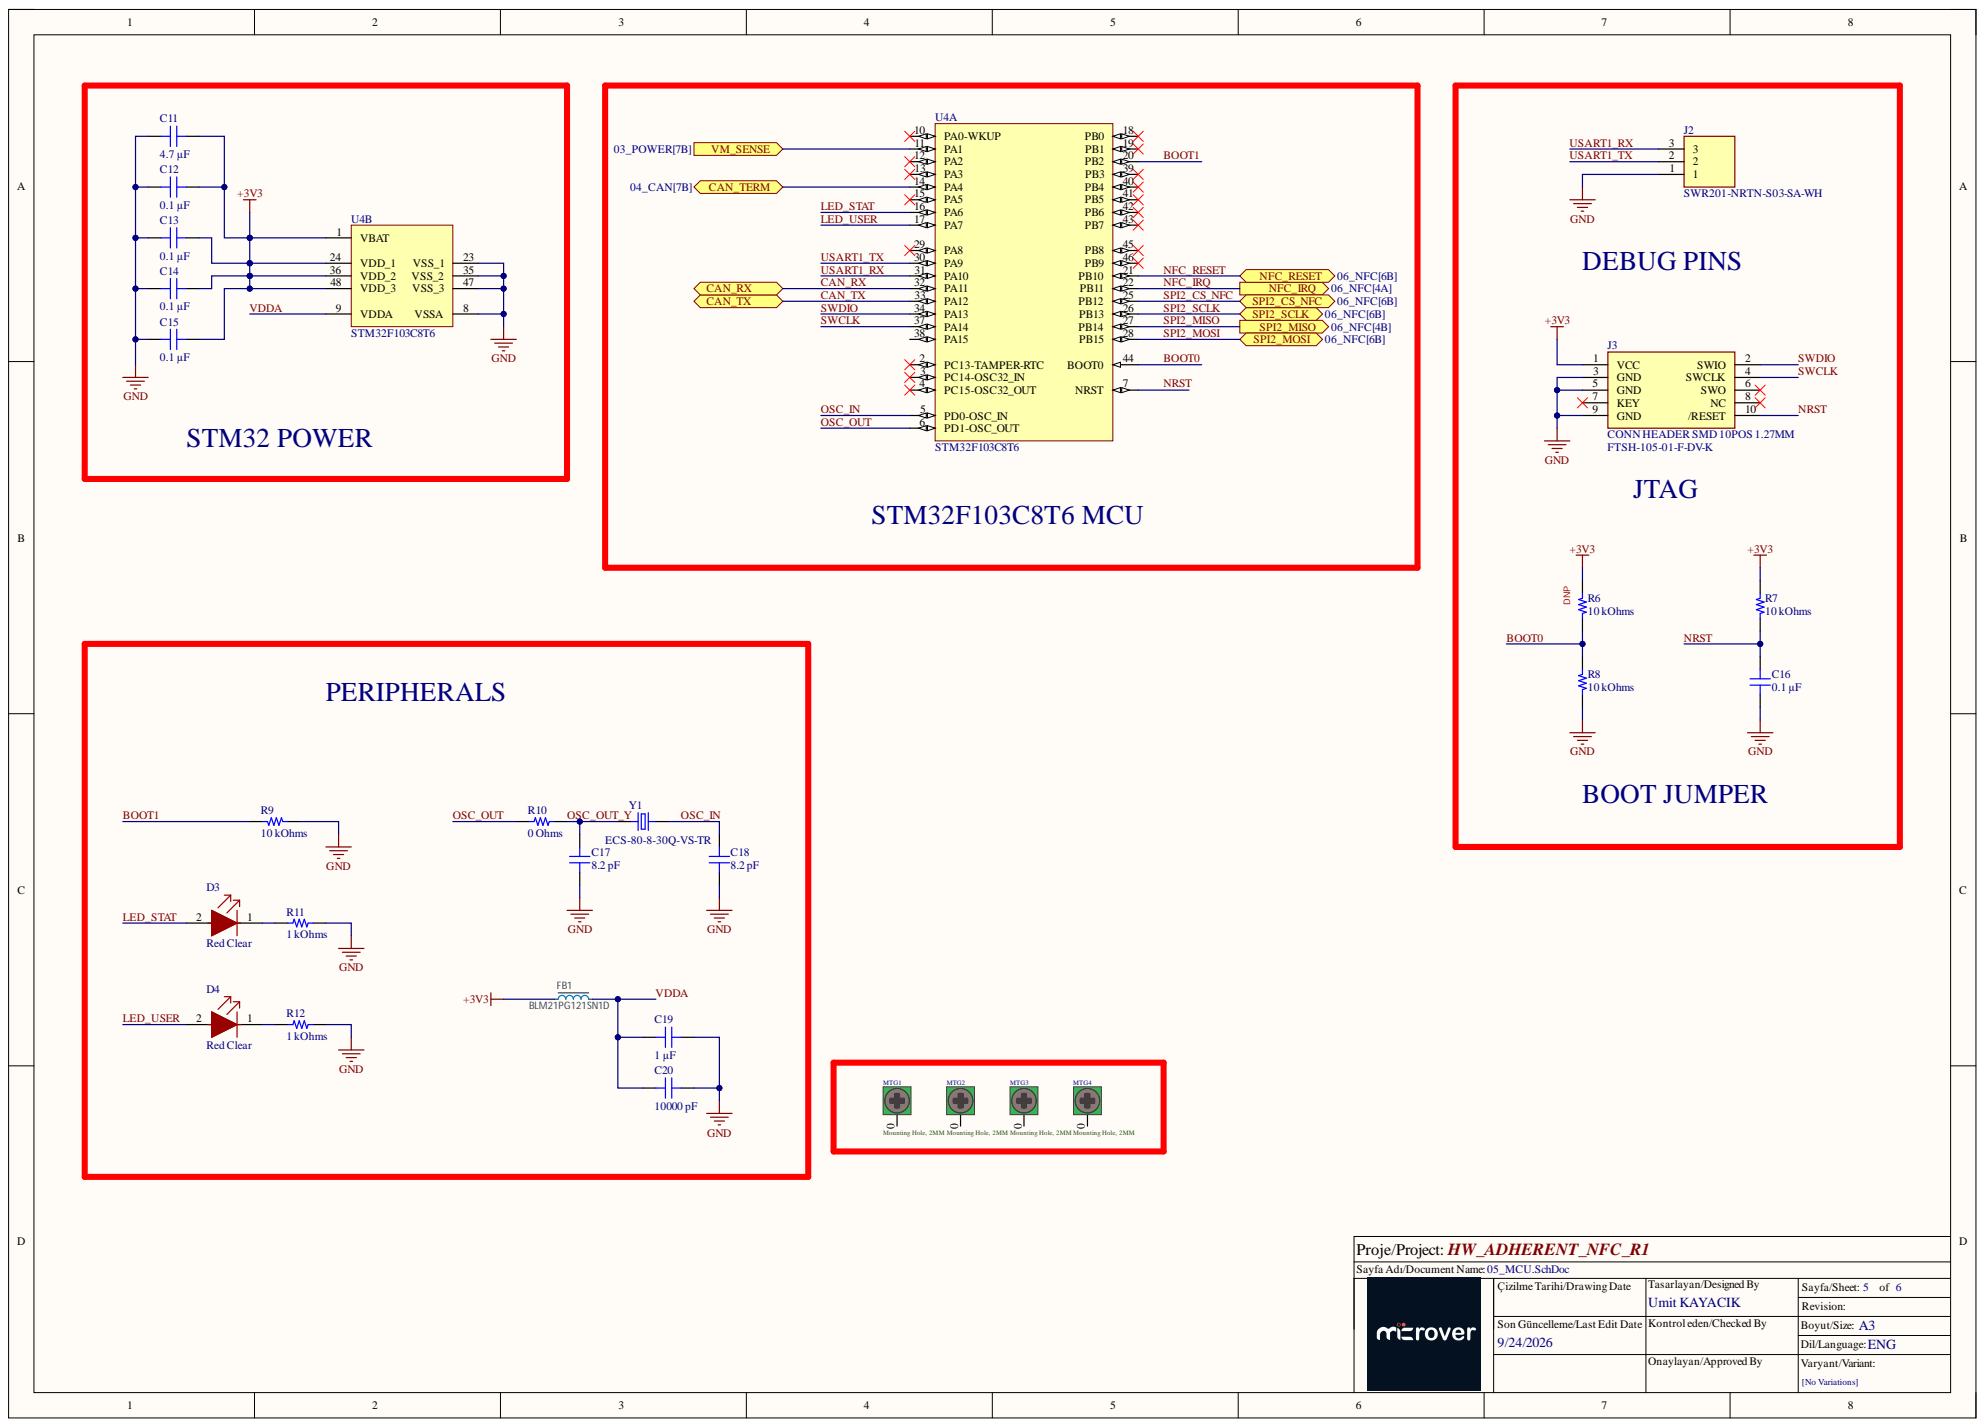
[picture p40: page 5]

Sayfa Adı/Document Name:

Son Güncelleme/Last Edit Date

Kontrol eden/Checked By

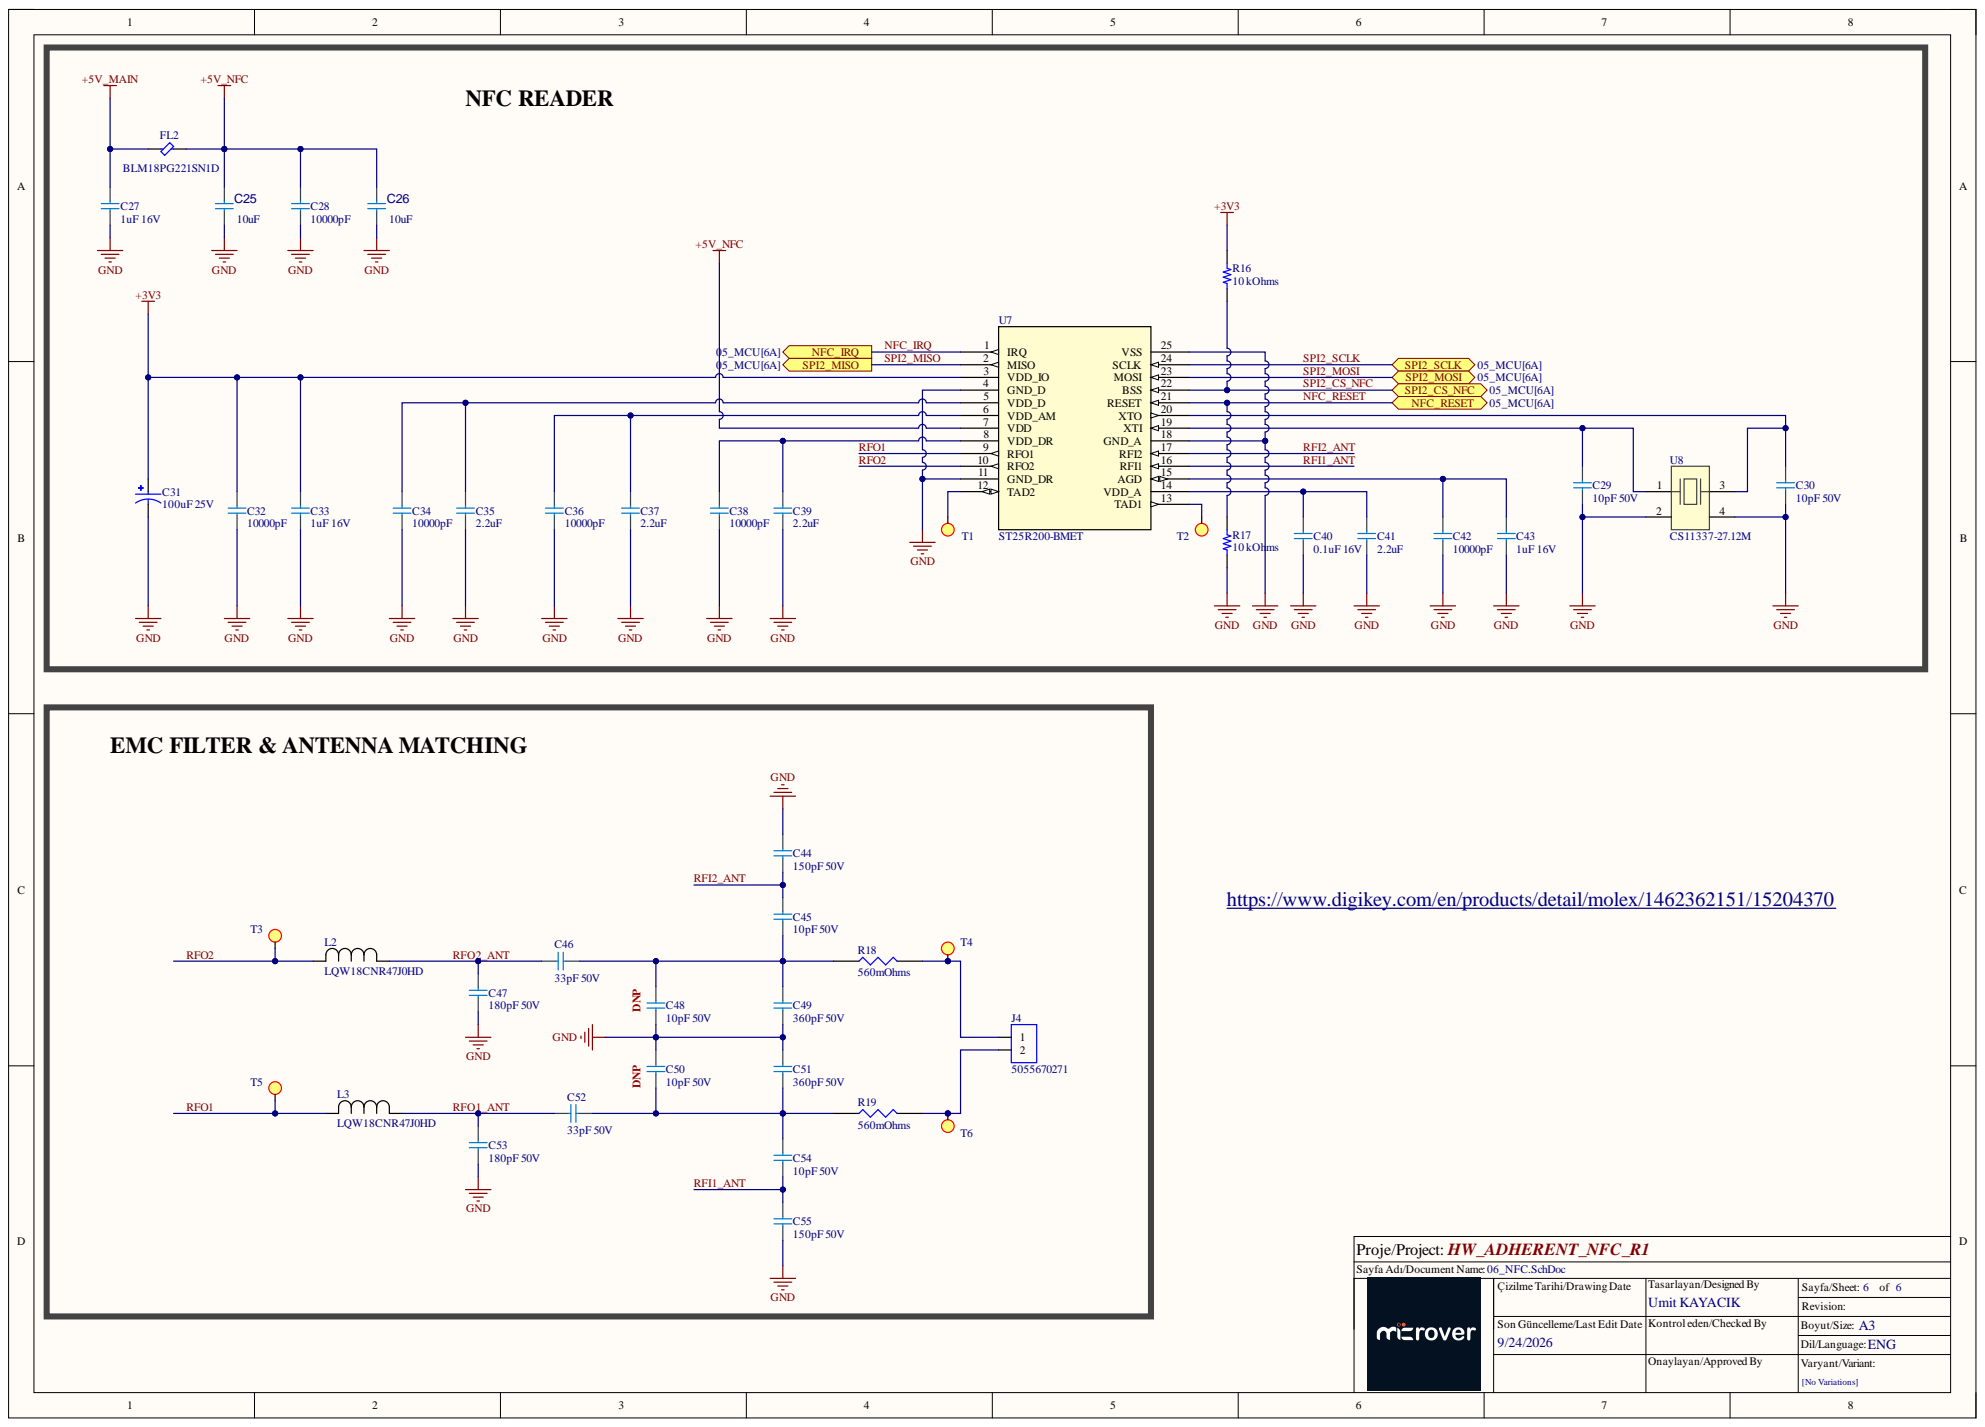
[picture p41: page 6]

VDD_D 5
VDD_AM 6
VDD 7
VDD_DR 8 | RFI2_ANT

RFO1 RFO2 | | RFO1 9 RFO2 10 GND_DR 11

EMC FILTER & ANTENNA MATCHING

https://www.digikey.com/en/products/detail/molex/1462362151/15204370

Sayfa Adı/Document Name:

Son Güncelleme/Last Edit Date

Kontrol eden/Checked By

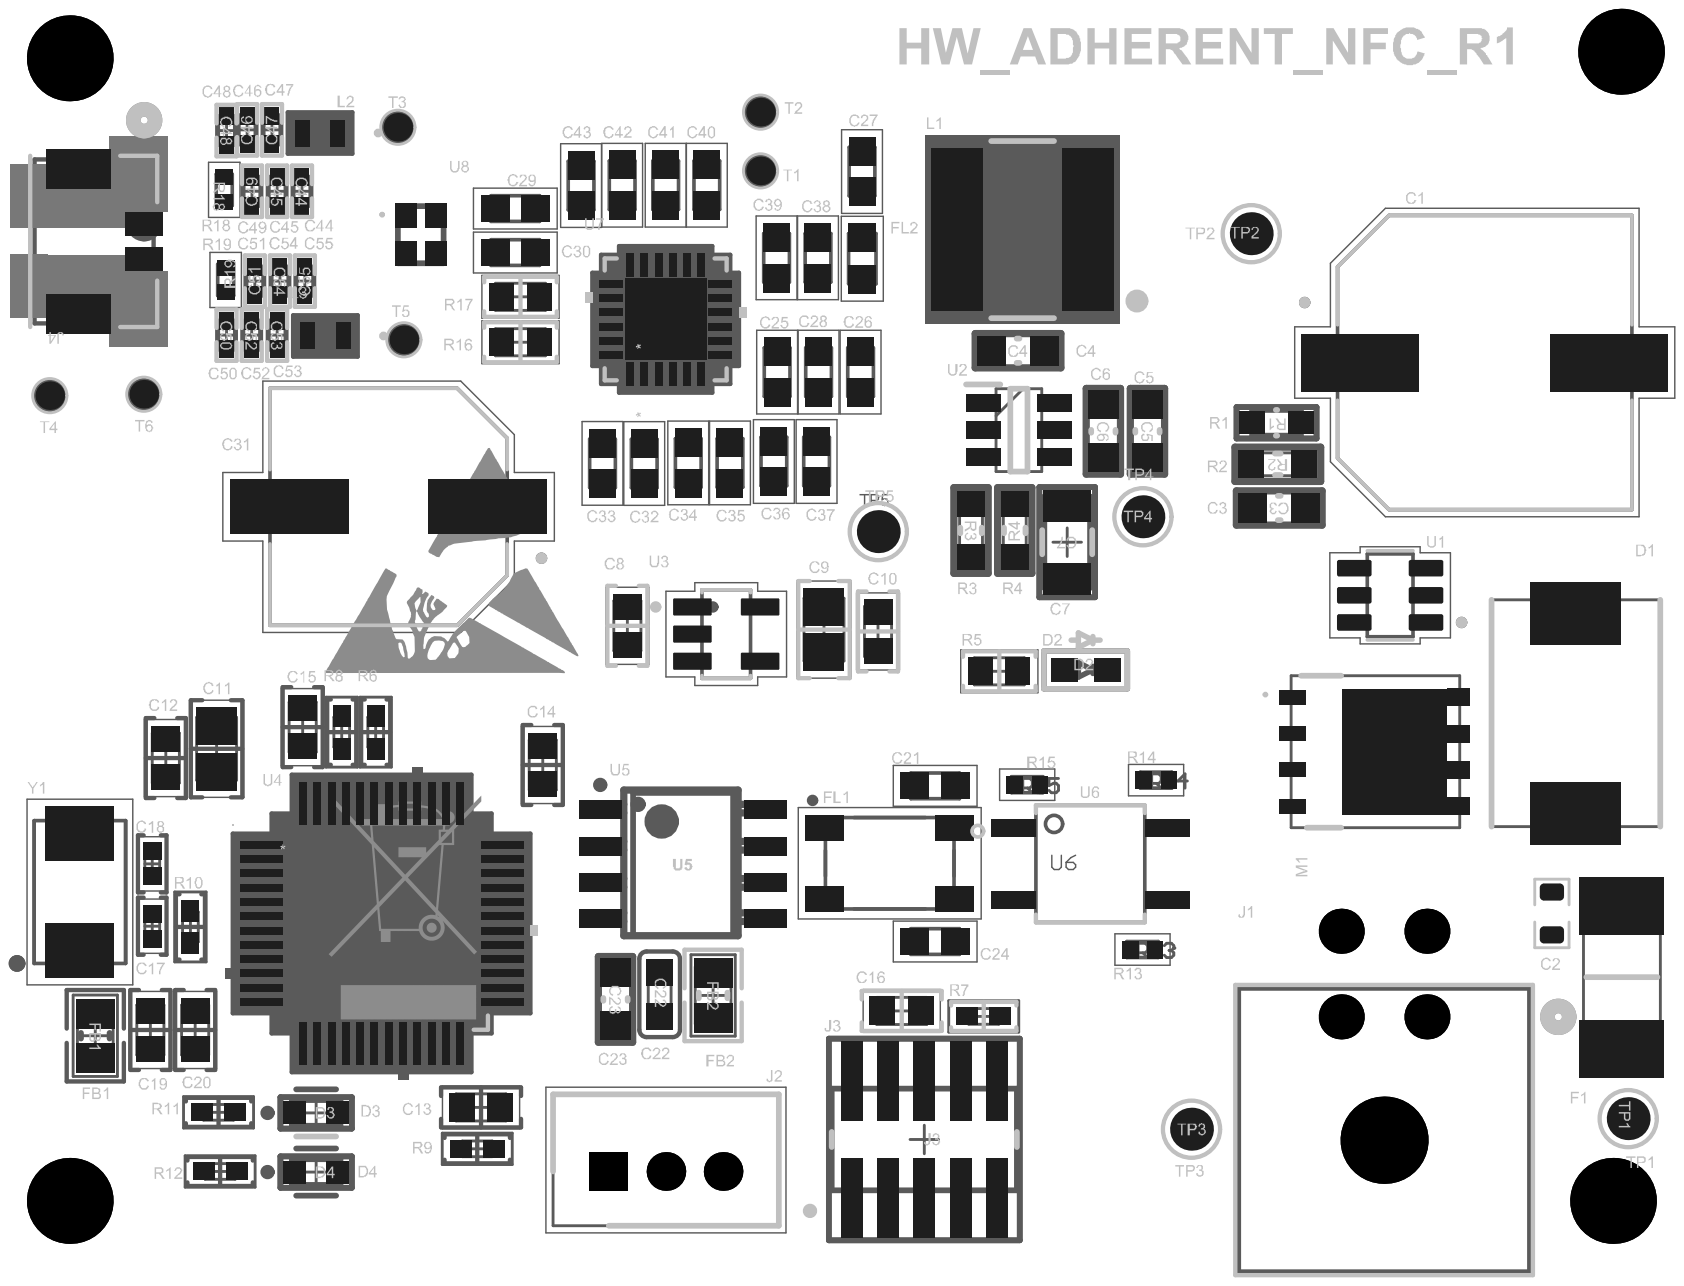
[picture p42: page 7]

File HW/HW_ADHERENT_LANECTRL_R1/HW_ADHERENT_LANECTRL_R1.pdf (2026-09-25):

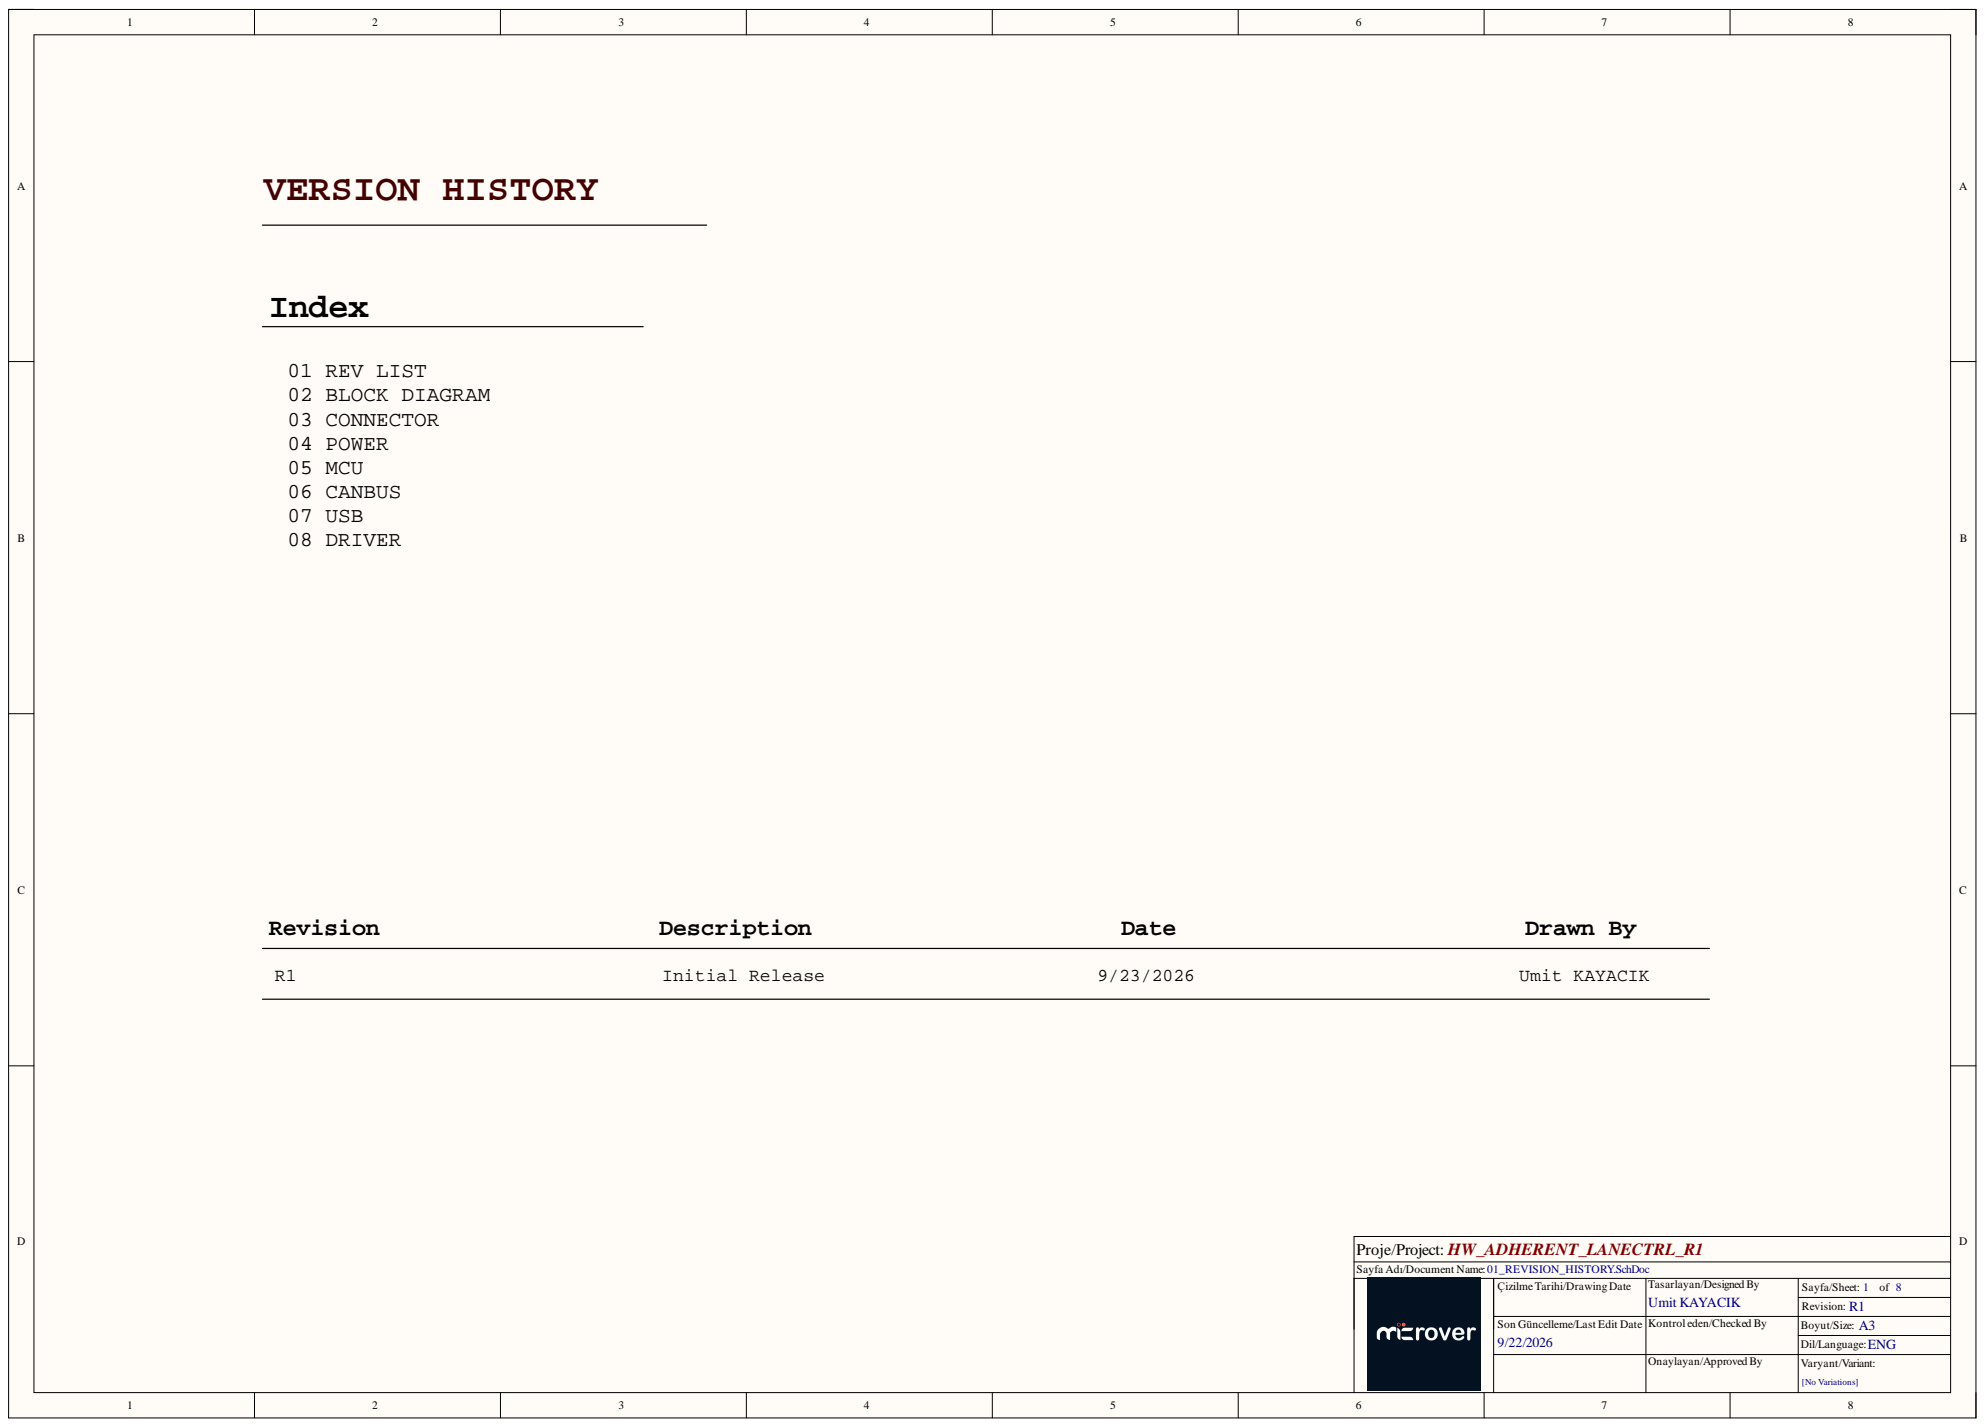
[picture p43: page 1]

Sayfa Adı/Document Name:

Son Güncelleme/Last Edit Date

Kontrol eden/Checked By

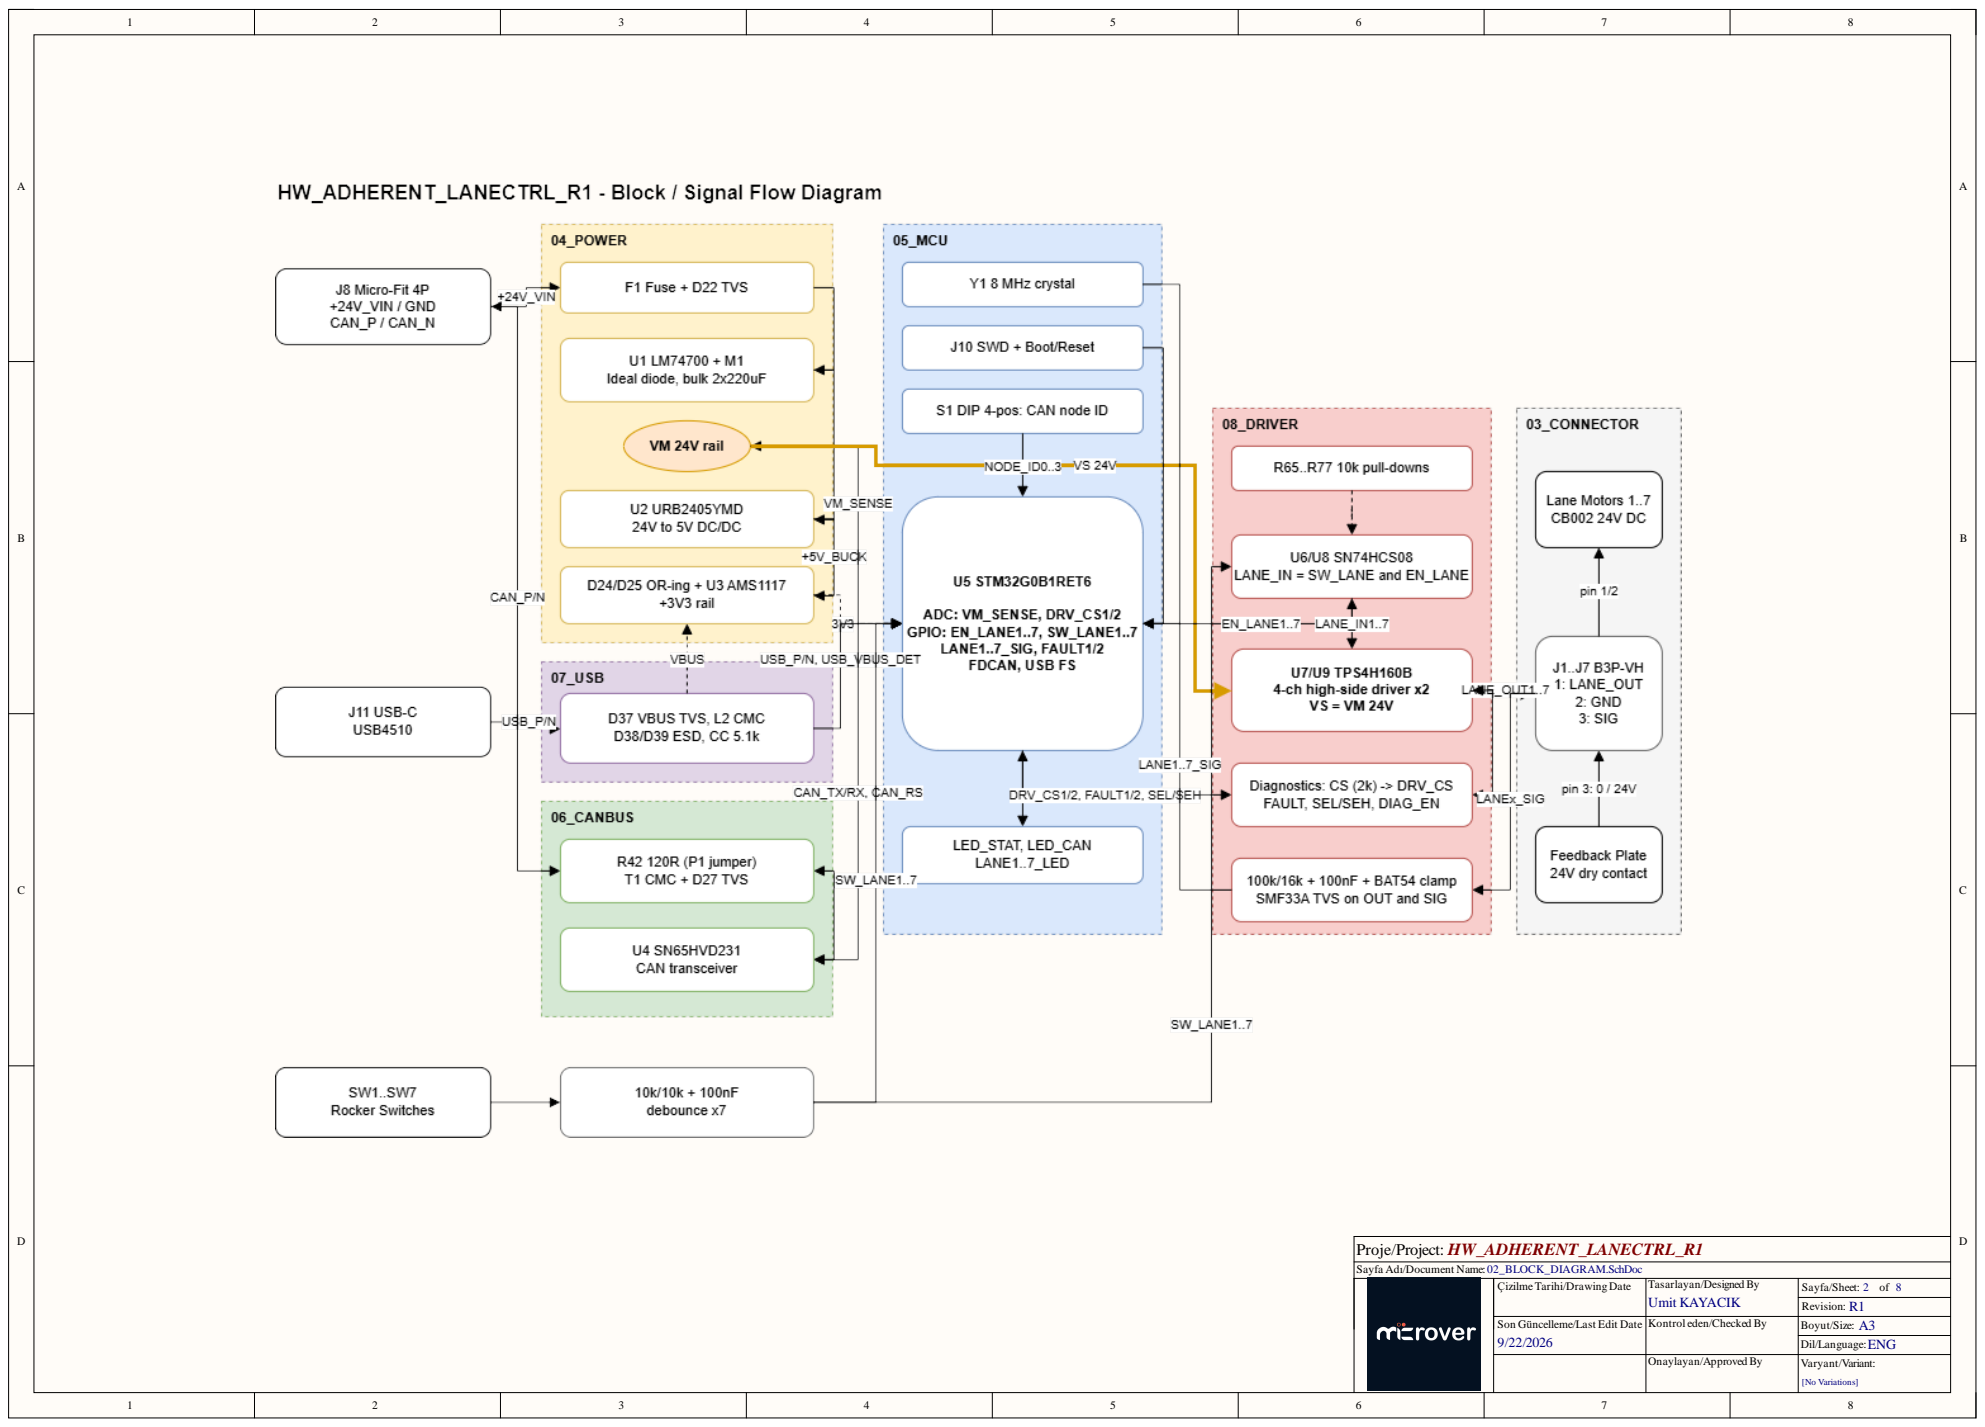
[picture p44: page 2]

Sayfa Adı/Document Name:

Son Güncelleme/Last Edit Date

Kontrol eden/Checked By

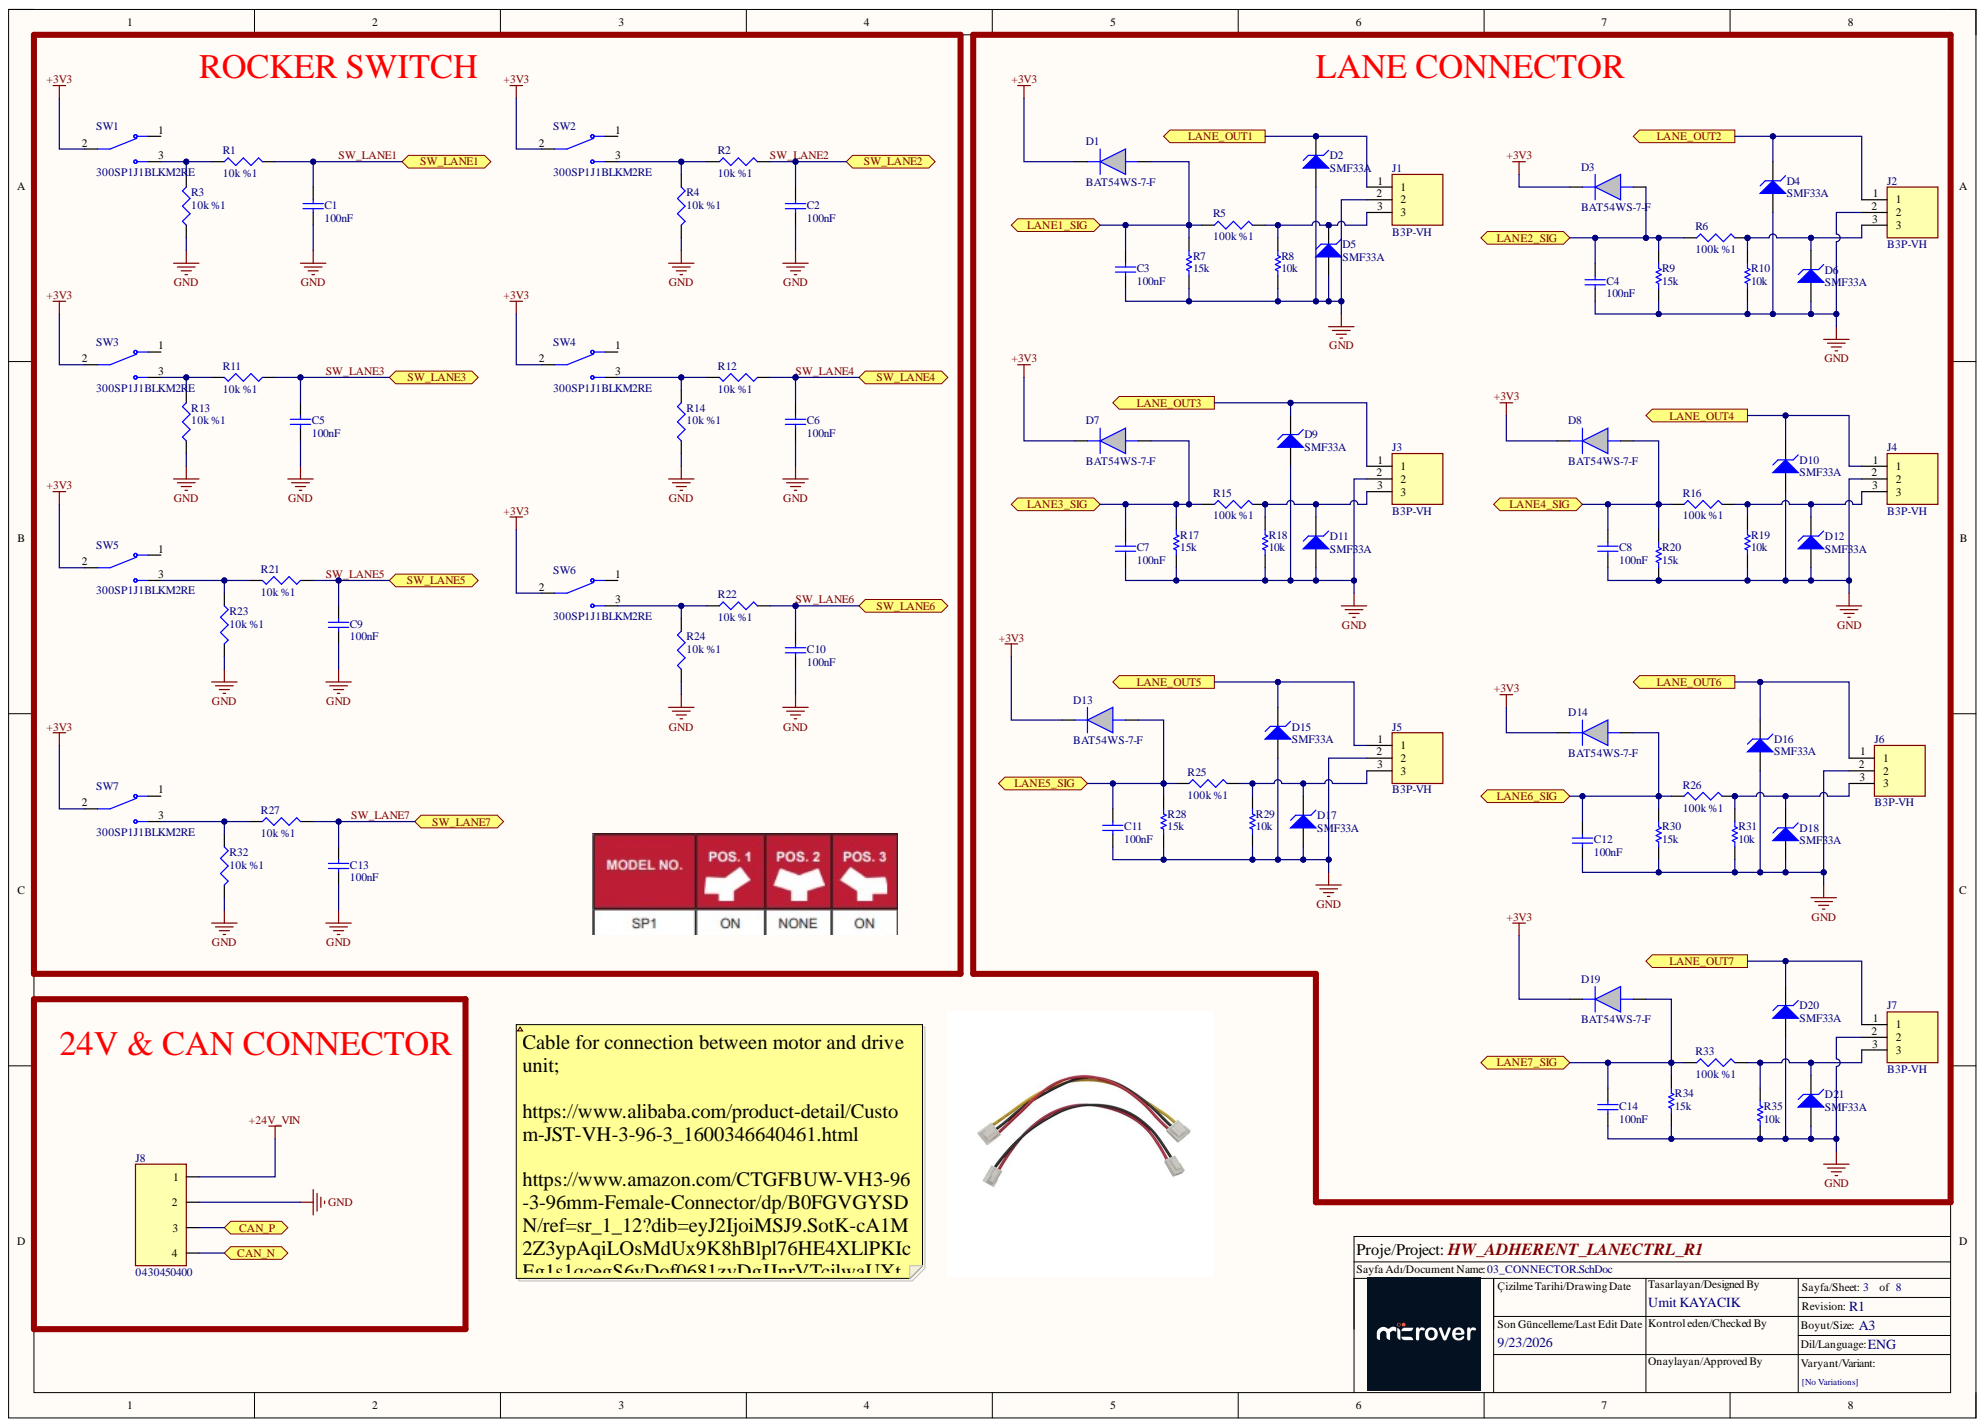
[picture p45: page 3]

Cable for connection between motor and drive
unit;

https://www.alibaba.com/product-detail/Custo
m-JST-VH-3-96-3_1600346640461.html

https://www.amazon.com/CTGFBUW-VH3-96
-3-96mm-Female-Connector/dp/B0FGVGYSD
N/ref=sr_1_12?dib=eyJ2IjoiMSJ9.SotK-cA1M
2Z3ypAqiLOsMdUx9K8hBlpl76HE4XLlPKIc
Eg1s1qcegS6vDof0681zvDgJJnrVTcjlwaUXt

Sayfa Adı/Document Name:

ÇizilmeTarihi/DrawingDate | Tasarlayan/Designed By Umit KAYACIK

Son Güncelleme/Last Edit Date 9/23/2026 | Kontrol eden/Checked By

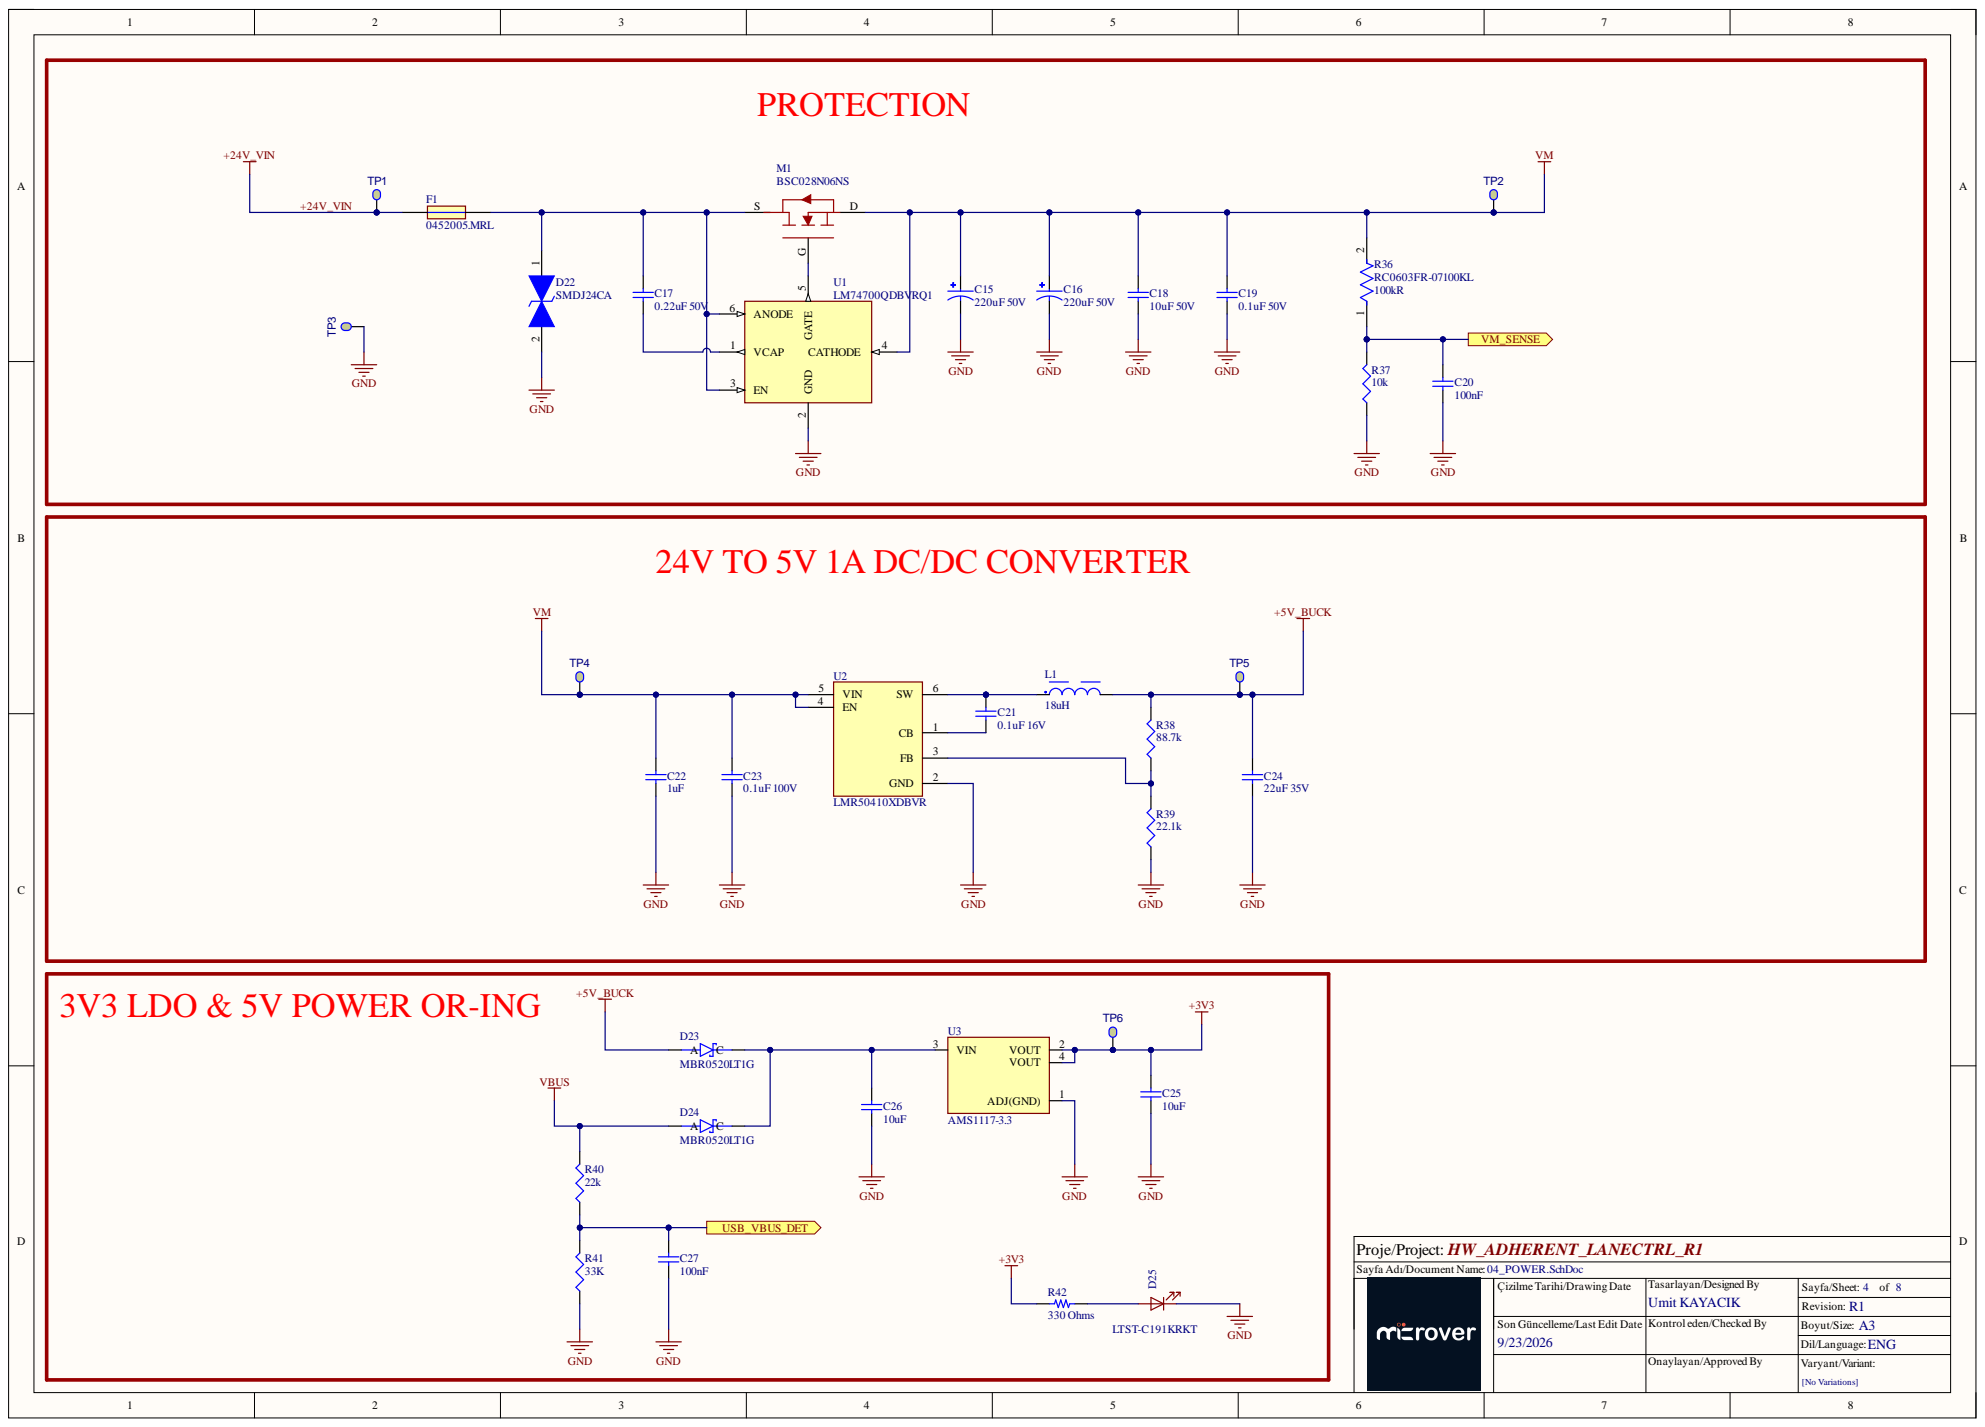
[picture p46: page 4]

24V TO 5V 1A DC/DC CONVERTER

3V3 LDO & 5V POWER OR-ING

Sayfa Adı/Document Name:

Son Güncelleme/Last Edit Date

Kontrol eden/Checked By

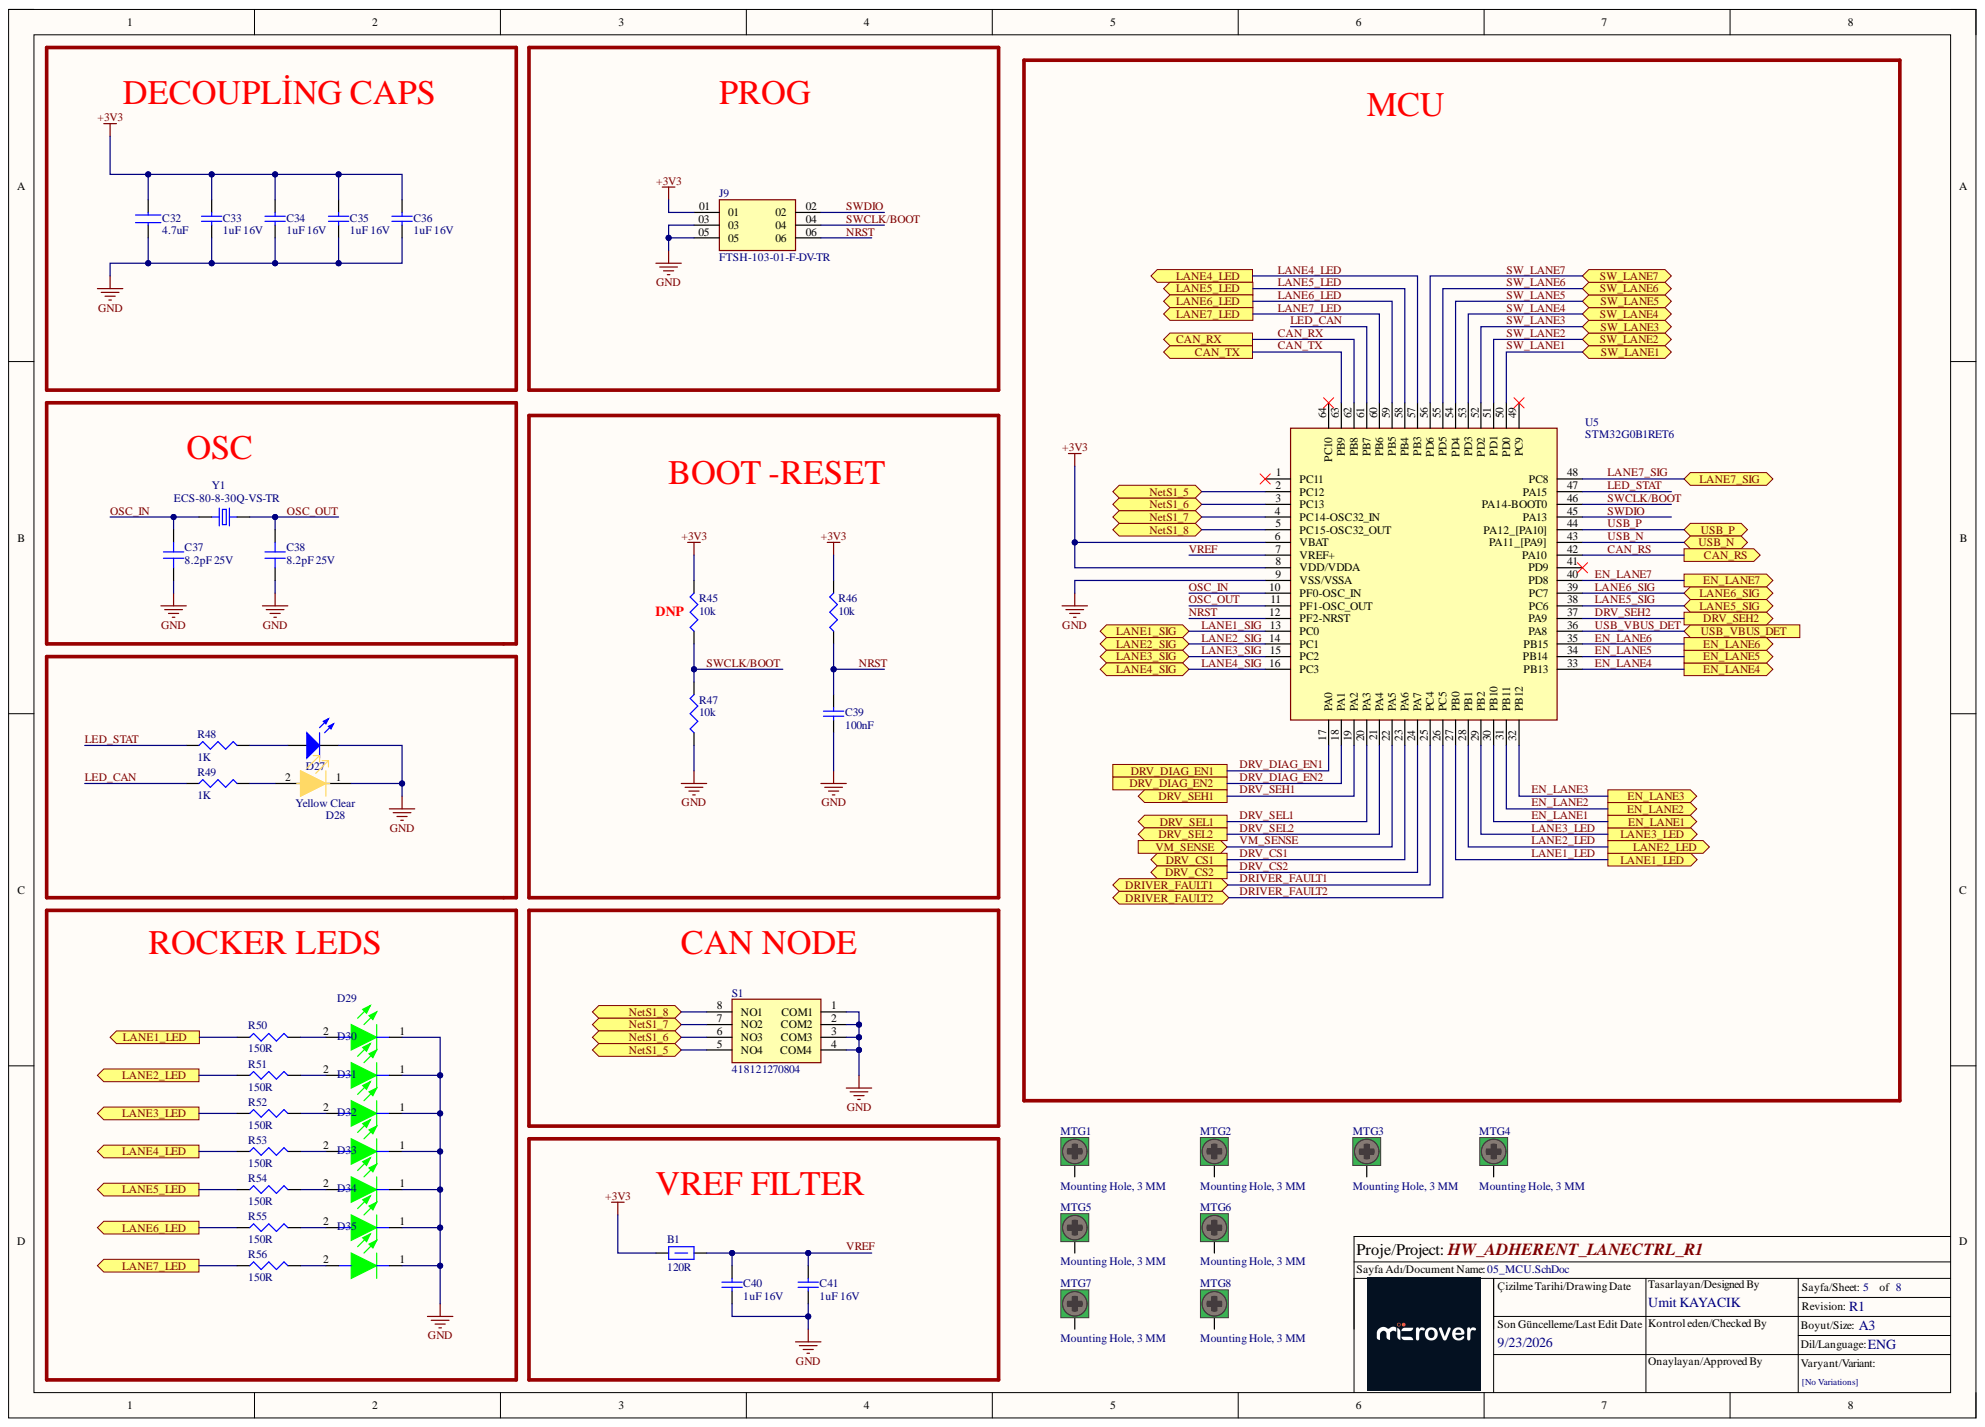
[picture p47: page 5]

VM_SENSE | | LANE2_LED
DRV_CS1 | LANE1_LED

Sayfa Adı/Document Name:

Son Güncelleme/Last Edit Date

Kontrol eden/Checked By



Sayfa Adı/Document Name:

Son Güncelleme/Last Edit Date

Kontrol eden/Checked By


Sayfa Adı/Document Name:

Son Güncelleme/Last Edit Date

Kontrol eden/Checked By

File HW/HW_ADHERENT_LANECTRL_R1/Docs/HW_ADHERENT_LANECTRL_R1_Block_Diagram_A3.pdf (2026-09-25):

# HW_ADHERENT_LANECTRL_R1 — Block Diagram


7-lane conveyor motor controller (CAN / USB) · signal flow: right → left · inputs on the right, lane outputs on the left

VM — protected 24 V rail (C15/C16 2 × 220 µF) → U7/U9 VS

Power rail (see POWER RAILS table)

Circuit block (designator, part no.)

Bidirectional bus (CAN, USB)

D36 SMAJ5.0A VBUS TVS, C42
L2 90 Ω CMC · D37/D38 RF2945 ESD
R57/R58 5.1 kΩ CC pull-downs

03_CONNECTOR
LANE CONNECTOR
Plate-signal input ×7
100 kΩ / 15 kΩ divider
10 kΩ pull-down, 100 nF
BAT54 clamp to +3V3

STM32G0B1RET6
Arm Cortex-M0+ MCU
FDCAN · USB FS · ADC

10 kΩ series + 10 kΩ pull-down + 100 nF

1. Lane x runs only when its rocker switch is ON and the MCU drives
EN_LANEx high: LANE_INx = SW_LANEx AND EN_LANEx (U6/U8). 10 kΩ
pull-downs hold EN_LANEx low while the MCU is in reset.
2. J1…J7 pinout: 1 = LANE_OUTx (switched VM), 2 = GND, 3 = plate-switch
signal (0 / 24 V), divided to ≈3 V at LANEx_SIG.
3. U7/U9 report load current on CS (channel selected by SEH/SEL) and faults
on FAULT; U5 reads both.
4. The CAN node ID is set with S1. The 120 Ω termination (R43) is enabled
with jumper P1.
5. Designators and values follow HW_ADHERENT_LANECTRL_R1, sheets
03–08 (23 Sep 2026).

MCU support
Y1 8 MHz crystal
J9 SWD (FTSH-103)
BOOT0 / NRST
S1 DIP-4: CAN node ID
VREF filter (B1)

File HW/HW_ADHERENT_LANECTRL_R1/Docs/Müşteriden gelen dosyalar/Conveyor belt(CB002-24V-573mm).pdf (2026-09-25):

Technical specifications:

Voltage | 24VDC
No load current | ≤0.2A
No load speed | 5.8cm/S
Rated load | ≤6KG
Motor type | DC Brushed Motor

Wiring(from left to right):
1 connected to positive pole of power supply
2 connected to negative pole of power supply
3 connected to Signal

Ningbo Derry E&M Tech Co., Ltd | CB002-24V-573mm

Conveyor Belt

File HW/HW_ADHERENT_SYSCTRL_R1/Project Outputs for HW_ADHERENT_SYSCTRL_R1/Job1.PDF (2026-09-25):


Sayfa Adı/Document Name:

01_REVISION_HISTORY.SchDoc
Çizilme Tarihi/Drawing Date

Son Güncelleme/Last Edit Date

Kontrol eden/Checked By


Sayfa Adı/Document Name:

02_BLOCK_DIAGRAM.SchDoc
Çizilme Tarihi/Drawing Date

Son Güncelleme/Last Edit Date

Kontrol eden/Checked By







Sayfa Adı/Document Name:

05_MCU.SchDoc
Çizilme Tarihi/Drawing Date

Son Güncelleme/Last Edit Date

Kontrol eden/Checked By


Sayfa Adı/Document Name:

06_DRIVER.SchDoc
Çizilme Tarihi/Drawing Date

Son Güncelleme/Last Edit Date

Kontrol eden/Checked By


CPC1 0 1


7 | 3 0
8 | | 2 9
9 | | 2 8
1 0 | | 2 7

SRBH | | | | CH UCK _E N N

SPI_SC K
SPI_MO S I


PU L-_ X | | | A LMX _ IN
DIR+_ X | | | G N D

DIR-_ Y | +2 4 V _ M O T
E N A +_ Y | BRK-_ Y



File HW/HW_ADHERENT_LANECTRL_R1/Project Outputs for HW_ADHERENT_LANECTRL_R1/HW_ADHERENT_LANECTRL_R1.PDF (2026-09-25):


Sayfa Adı/Document Name:

01_REVISION_HISTORY.SchDoc
Çizilme Tarihi/Drawing Date

Son Güncelleme/Last Edit Date

Kontrol eden/Checked By


Sayfa Adı/Document Name:

02_BLOCK_DIAGRAM.SchDoc
Çizilme Tarihi/Drawing Date


Sayfa Adı/Document Name:

03_CONNECTOR.SchDoc
Çizilme Tarihi/Drawing Date


VCAP 1

24V TO 5V 1A DC/DC CONVERTER

Sayfa Adı/Document Name:

04_POWER.SchDoc
Çizilme Tarihi/Drawing Date


DRV_SEL2 | | | LANE3_LED
VM_SENSE | | LANE2_LED
DRV_CS1 | LANE1_LED

Sayfa Adı/Document Name:

05_MCU.SchDoc
Çizilme Tarihi/Drawing Date



Sayfa Adı/Document Name:

07_USB.SchDoc
Çizilme Tarihi/Drawing Date


Sayfa Adı/Document Name:

08_DRIVER.SchDoc
Çizilme Tarihi/Drawing Date

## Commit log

2026-09-25 Import Adherent project into Microver repository
    [01_REVISION_HISTORY.SchDoc, 02_BLOCK_DIAGRAM.SchDoc, 03_POWER.SchDoc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]
2026-09-25 Remove superseded SYS deliverable revisions
    [APDU_Electrical_Tables_R14.xlsx, APDU_Electrical_Tables_R15.xlsx, APDU_Electrical_Tables_R16.xlsx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]
2026-09-25 Organize hardware folders, rename IOCTRL, and add bracket and Ethernet references
    [01_REVISION_HISTORY.SchDoc, 02_BLOCK_DIAGRAM.SchDoc, 03_POWER.SchDoc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]
2026-09-25 Remove redundant board STEP models archive
2026-09-25 Remove redundant wiring diagram archive
2026-09-25 Align R27 system documents and add diagram component spreadsheet
    [ADHERENT_System_Diagram_Components_R27.xlsx, APDU_Electrical_Tables_R23.xlsx, APDU_Electrical_Tables_R27.xlsx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]
2026-09-25 Tag diagram component categories and add project landing page
2026-09-25 Reconcile SYSCTRL schedules and select Molex NFC antenna
    [ADHERENT_System_Diagram_Components_R27.xlsx, APDU_Electrical_Tables_R27.xlsx]
2026-09-25 Move board STEP models into MEC and update references
    [IOCTRL_Provisional_Placement_R1.step, MAINCTRL_MYD-YF13X_Provisional_Placement_R1.step, myc-yf135-v02_asm.stp]
2026-09-25 Simplify customer parts sheet and align diagram references and document names
    [ADHERENT_Electrical_Tables.xlsx, ADHERENT_Mechanical_BOM.xlsx, ADHERENT_System_Diagram_Components_R27.xlsx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]
2026-09-25 HW_ADHERENT_LANECTRL_R1 step exported.
    [01_REVISION_HISTORY.SchDoc, 02_BLOCK_DIAGRAM.SchDoc, 03_CONNECTOR.SchDoc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]
2026-09-25 Fix Excel repair warning caused by duplicate print margins
    [ADHERENT_Electrical_Tables.xlsx]
2026-09-25 Update presentation to used system interfaces and current NFC architecture
2026-09-25 HW_ADHERENT_NFC_R1 initial commit
    [01_REVISION_HISTORY.SchDoc, 02_BLOCK_DIAGRAM.SchDoc, 03_POWER.SchDoc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]
2026-09-25 Layer board mount added R1
    [0_762m_E2i_17_025_028_0___1025_34P_A1_4.STEP.SLDPRT, 1129A466_High-Temperature Rubber Seal_1129A466.STEP.SLDPRT, 120 cc ROUND BOTTLE BODY.STEP.SLDPRT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]
2026-09-25 HW_ADHERENT_NFC_R1 step update
    [HW_ADHERENT_NFC_R1.PcbDoc, HW_ADHERENT_NFC_R1.step]
2026-09-25 NFS board mountıng R1
    [1277A83_Steel Drawer Slides.STEP.SLDASM, 1462362151-1.SLDPRT, 1462362151.SLDPRT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]
2026-09-25 HW_ADHERENT_SYSCTRL_R1 initial commit.
    [01_REVISION_HISTORY.SchDoc, 02_BLOCK_DIAGRAM.SchDoc, 03_POWER1.SchDoc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]
2026-09-25 HW_ADHERENT_LANECTRL_R1 step, connector location
    [HW_ADHERENT_LANECTRL_R1.PcbDoc]
2026-09-25 Excel update.
    [ADHERENT_Electrical_Tables.xlsx]
2026-09-25 Diagram update.
    [ADHERENT_Electrical_Tables.xlsx, ADHERENT_Mechanical_BOM.xlsx]
2026-09-25 Board Converts
    [1277A83_Steel Drawer Slides.STEP.SLDASM, 60cc ROUND BOTTLE ASSY.STEP.SLDASM, HW_ADHERENT_NFC_R1.SLDPRT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]
2026-09-25 Harness wiring diagram and system wiring diagram
